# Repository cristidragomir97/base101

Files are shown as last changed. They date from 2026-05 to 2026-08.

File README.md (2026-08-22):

# base101

<p align="center">
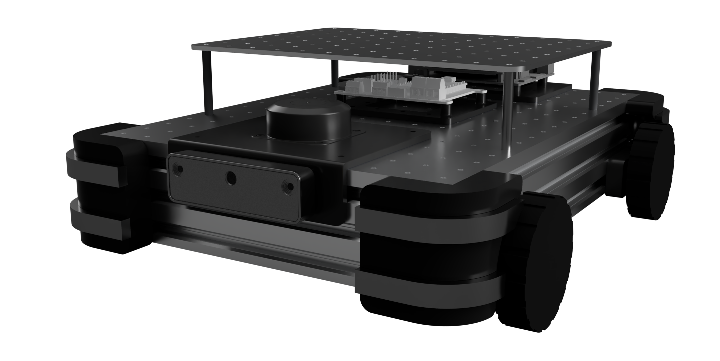
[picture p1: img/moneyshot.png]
base101
      
</p>

**An open-source mobile base you can actually build things on.**

Every robot project that has to *move* starts the same way: you want to work on
the interesting part — the arm, the perception, the behaviour — and instead you
spend six weeks building a cart. Then you want to add a lidar, and there's
nowhere to put it. Then you add a compute board, and you're drilling into your
own chassis. Most open mobile bases are somebody's finished robot, published as
if it were a platform, and the moment your payload differs from theirs you're
forking it.

base101 is the other thing: a chassis whose entire job is to carry whatever you
bolt to it. A machined deck with a grid of tapped holes, four direct-drive hub
motors, a lidar and a depth camera already wired into ROS 2, and a one-line
mounting point for the [mod101](https://github.com/robocore-dev/mod101) arm. It
drives, maps and navigates on day one, so the part you actually care about can
start on day two.

- 🧱 **Real frame, not a printed box** — 60×20 aluminum extrusion, PLA-CF printed parts only where they earn their place.
- 🕳️ **A deck you can bolt anything to** — 280×400 mm aluminum plate, 3 mm thick, CNC-machined ORP compatible grid. 
- 💥 **TPU corners** — printed bumpers absorb the collisions you're going to have, and spare your furniture while you tune the planner.
- 🛞 **4WD skid steer on hub motors** — four Waveshare DDSM210 direct-drive hubs. No gearboxes, no belts, nothing to slip: the wheel *is* the motor.
- 💪 **Sized for a 5–8 kg robot** — 97 N of tractive force at stall, enough to push 8 kg up a 10% incline. Arm, battery and compute, and it still clears the threshold into the next room.
- 🛰️ **360° lidar** — RPLidar C1 up front, `/scan` at ~10 Hz into SLAM and Nav2. Mapping and autonomous nav work out of the box.
- 👁️ **Swappable depth camera** — RealSense D435 or Luxonis OAK-D on the same bracket, one launch arg apart. Same topics, same frames.
- 🧠 **One board runs the base** — built around the [link101](https://github.com/robocore-dev/link101-hw)
- 🤖 **Carries the [mod101](https://github.com/robocore-dev/mod101) arm** — one xacro line, plus MoveIt config for the *composed* robot: the arm knows the chassis it stands on.

**Here to build the robot?** The hardware is described below. **Here to run the
code?** Start with [Getting started](#getting-started).

---

## Getting started

You'll need ROS 2 Jazzy on Ubuntu 24.04. Everything else (Gazebo Harmonic,
`ros2_control`, `gz_ros2_control`) comes from apt.

**Just the chassis** — no arm, nothing else to build first:

```bash
cd ~/robots/base101
colcon build --symlink-install --cmake-args -DPython3_EXECUTABLE=/usr/bin/python3
source install/setup.bash

ros2 launch base101_bringup_gazebo sim.launch.py
```

That's a robot in Gazebo, driving, scanning, publishing `/odom` — open
`http://localhost:8888/` and drive it around from the browser.

**With the arm**, mod101 has to be built and sourced first (it's the underlay;
base101 sits on top of it):

```bash
cd ~/robots/mod101 && colcon build --symlink-install && source install/setup.bash
cd ~/robots/base101
colcon build --symlink-install --cmake-args -DPython3_EXECUTABLE=/usr/bin/python3
source install/setup.bash

ros2 launch base101_bringup_gazebo sim.launch.py arm:=true
```

**This is the only place the build is documented** — everything below assumes
you've run it. Two footnotes that will save you an afternoon:

- **The `Python3_EXECUTABLE` pin isn't arm-specific.** It applies to every build
  here, and it guards against a stray non-system python on `PATH` breaking
  ament's `package.xml` parsing and `rosidl`'s `em` import. Tired of typing it?
  Set it once in `~/.colcon/defaults.yaml` — see [`HARDWARE.md`](HARDWARE.md).
- **`rosdep` has never heard of `mod101_description`.** base101 deliberately
  does not declare it (the arm include sits inside a `<xacro:if>`, so an
  armless workspace never resolves it), but if you run `rosdep install` with
  mod101 present, pass `--skip-keys mod101_description`.

### Things to try

```bash
ros2 launch base101_bringup_gazebo sim.launch.py                    # bare chassis, sticky_floor world
ros2 launch base101_bringup_gazebo sim.launch.py arm:=true          # chassis + 1 mod101 arm
ros2 launch base101_bringup_gazebo sim.launch.py world:=empty.sdf   # pick a world
ros2 launch base101_bringup_gazebo sim.launch.py camera:=oak_d      # Luxonis OAK-D instead of the D435
ros2 launch base101_bringup_gazebo sim.launch.py nav:=false         # no SLAM/Nav2, just the robot
ros2 launch base101_bringup_gazebo sim.launch.py agent:=false       # no robocore agent
ros2 launch base101_bringup_hw     display.launch.py                # rviz only, no sim
```

`camera:=realsense|oak_d` picks which depth module hangs off the front bracket
(default `realsense`). It only swaps the mesh and the simulated FOV — topics
stay `/base_camera/*` and frames stay `camera_link` / `camera_optical_frame`
either way, so nothing downstream notices. Both `sim.launch.py` and
`display.launch.py` take it.

SLAM, Nav2 and the robocore agent all come up with the sim by default
(`nav:=false` / `slam:=false` / `agent:=false` to skip). Nav2 alone is inert —
it blocks in `Activating` until something publishes the `map` frame — so SLAM
and Nav2 start together.

The agent picks its profile from `engine/profiles/` by configuration:
`base101.yaml` armless, `base101_arm.yaml` with `arm:=true`. Override with
`profile:=/path/to.yaml` or `$ROBOCORE_PROFILE`; it serves JSON-RPC on
`ws://:10101` and `/tmp/robocore.sock` (`agent_port:=` / `agent_socket:=`).

Manual test procedures for every variant, tool and launch combination are in
[`docs/testing.md`](docs/testing.md).

### On the real robot

Motors, IMU and lidar all hang off the Axon 2 board and talk to ROS 2 over
zenoh, so bringup is two lines:

```bash
export RMW_IMPLEMENTATION=rmw_zenoh_cpp
ros2 launch base101_bringup_hw robot.launch.py
```

Firmware, the zenoh router, serial devices and udev rules:
[`HARDWARE.md`](HARDWARE.md).

## Adding the mod101 arm

**The whole point of the deck is that something goes on it.** The obvious
something is [mod101](https://github.com/robocore-dev/mod101), a 5+1 DOF arm
that's designed to be embedded — it's a prefix-parameterised xacro macro, so
base101 mounts it with one call and gets joints `arm_1…6`.

```bash
ros2 launch base101_bringup_gazebo sim.launch.py arm:=true                   # jaws gripper
ros2 launch base101_bringup_gazebo sim.launch.py arm:=true arm_tool:=parallel
ros2 launch base101_bringup_hw display.launch.py arm:=true                   # rviz only
```

You don't configure the arm here. Rail lengths, servo mounts and the active
tool all come from `mod101_config.xacro` — whatever mod101's web configurator
last saved. Resize the arm over there, rebuild here, done.

### How the two repos meet

mod101 is an **underlay**: built and sourced first, it puts its packages on
`AMENT_PREFIX_PATH`, and base101 is the overlay on top. **Nothing in mod101
knows base101 exists.** base101 reaches back across the boundary in exactly
three places:

| Crossing | Where, in base101 | What it pulls from mod101 |
|---|---|---|
| **Geometry** | `base101_description/urdf/arm.xacro` | `<xacro:mod101_arm prefix="arm_" parent="top_plate_1">` from `mod101_macro.xacro` |
| **Semantics** | `base101_arm_moveit_config/srdf/base101_arm.srdf.xacro` | `<xacro:mod101_arm_srdf prefix="arm_" tool=…>` from `mod101_moveit_config` |
| **Build args** | both files above | `mod101_config.xacro` — rail lengths, servo mounts, active tool |

Two macro calls and one config file. No forked packages, no vendored meshes, no
duplicated URDF — which is what let the (now parked) dual-arm tower mount the
*same* macro twice, `left_arm_` / `right_arm_`, with zero changes upstream.

Two things worth knowing before they confuse you:

- **Only the `arm` variant crosses over.** The `simple` variant never touches
  the underlay, so a bare-chassis build needs no mod101 at all.
- **The prefix renames everything the macro emits.** `joint_base` becomes
  `arm_joint_base`, and the planning group `arm` becomes **`arm_arm`**. Every
  base101 config keys on the prefixed names. It reads badly and it is correct.

### Motion planning

```bash
ros2 launch base101_bringup_gazebo sim.launch.py arm:=true moveit:=true   # gazebo + move_group
```

This config exists because mod101's own only knows arm-vs-arm collisions — but
the arm can reach every part of the chassis it's bolted to, so the composed
robot needs its own self-collision matrix. The planning scene knows the robot,
not the world; [`docs/obstacle-awareness.md`](docs/obstacle-awareness.md)
covers where perceived obstacles should live relative to a picking layer.

One gotcha: the sim has to run with `arm_control:=moveit` so it spawns
`FollowJointTrajectory` controllers instead of the `Float64MultiArray` ones the
web sliders use — `moveit:=true` forces that for you. Details in
[`base101_arm_moveit_config/README.md`](src/base101_arm/base101_arm_moveit_config/README.md).

**Controllers** — arm and gripper are
`position_controllers/JointGroupPositionController`, commanded with
`std_msgs/Float64MultiArray` on `/<name>/commands`:

| Controller | Joints |
|---|---|
| `arm_controller` | `arm_joint_base, arm_joint_shoulder, arm_joint_elbow, arm_joint_wrist_tilt, arm_joint_wrist_roll` |
| `gripper_controller` | `arm_6` (the tool joint) |
| `diff_drive_controller` | wheels (via `twist_mux`) |

The wrist camera is bridged as `/arm_wrist_camera/image_raw`.

## Driving it from a browser

No joystick, no terminal, no extra install — two ways:

- **rosboard's "Joint sliders" card** (the good one): open
  `http://localhost:8888/`, pick **Joint sliders** in the System nav. One panel,
  a position slider for every controlled joint, initialised from the live robot
  pose with readouts and a re-sync button. Groups whose hardware isn't loaded
  hide themselves, and the card survives a reload. Base driving lives on the
  separate **Teleop** card. (Position commands deliberately *aren't* zeroed by
  the publish watchdog the way Twist is, so the arm holds its pose when the
  browser goes quiet.)
- **`base101_teleop`** — a zero-dependency fallback if rosboard is unhappy:
  `ros2 run base101_teleop server` → `http://localhost:8700/`. Same sliders plus
  a hold-to-drive base pad. See
  [`src/base101_teleop/README.md`](src/base101_teleop/README.md).

## Simulation

The robot runs in **Gazebo Sim** through `gz_ros2_control`, and the sim is
meant to be the default place you work — it publishes the same `/cmd_vel_*`,
`/odom`, `/scan`, `/joint_states` and `/base_camera/image_raw` topics the real
robot does, so code written against sim moves over unchanged.

Each variant takes a `simulator` xacro arg (`gazebo` | `none`) that decides
whether the URDF carries the sim `ros2_control` and extension tags; `none` is
the bare URDF for rviz and real hardware. Worlds and the gz↔ros bridge config
live in the shared `base101_worlds` package.

## How the workspace is put together

*Skip this unless you're adding a package — everything above works without it.*

It's a **shared core** plus one self-contained stack per **variant**
(`description` / `gazebo` / `control`). Variants are grouped into folders under
`src/` (`base101/`, `base101_arm/`); colcon discovers packages recursively, so
the folders are purely organisational. Packages parked out of the build live in
[`attic/`](attic/README.md).

**Model, config and worlds** — `src/base101/`

| Package | Type | Purpose |
|---|---|---|
| `base101_description` | ament_python | **The robot**: `base101.xacro` (one description, `arm:=` picks the configuration), chassis links/joints, sensors, materials, meshes. *Not launched directly.* |
| `base101_control` | ament_cmake | Tuning: `controllers.{sim,hw}.yaml`, `twist_mux.yaml`, and the hardware overlay `base101.hardware.xacro`. |
| `base101_control_plugin` | ament_cmake | `ros2_control` SystemInterface bridging wheel/arm/camera command+state interfaces to the Axon firmware's `/motor_manager/*` topics (zenoh). |
| `base101_worlds` | ament_cmake | Sim-common assets: Gazebo worlds, ros↔gz bridge, RViz preset. |

**Stacks** — own their own launch, composed by the bringup packages

| Package | Type | Purpose |
|---|---|---|
| `base101_slam` | ament_cmake | EKF (robot_localization) + slam_toolbox: `/map` and the `map->odom` TF. |
| `base101_nav` | ament_cmake | Nav2: planner, controller, bt_navigator, velocity smoother, behavior trees. |
| `base101_arm_moveit_config` | ament_cmake | `src/base101_arm/` — MoveIt semantics for the composed chassis+arm robot, and `move_group.launch.py`. |

**Bringup** — the only launches you type

| Package | Type | Purpose |
|---|---|---|
| `base101_bringup_gazebo` | ament_cmake | `sim.launch.py` — the whole robot in Gazebo: model, controllers, bridges, SLAM, Nav2, optionally arm + MoveIt. |
| `base101_bringup_hw` | ament_cmake | `robot.launch.py` — the same graph on real hardware, same argument names. Also owns `display.launch.py` (RViz only). |

Arm or no arm is the `arm:=` argument, not a package. Before the 2026-08
restructure it was six packages (`base101_simple_{description,gazebo,control}`
and `base101_arm_{description,gazebo,control}`) expressing one boolean — see
[`docs/bringup-restructure.md`](docs/bringup-restructure.md).

**Other tooling** — `src/`

| Package | Type | Purpose |
|---|---|---|
| `robocore_agent` | ament_python | Robocore (blueprint engine) agent: ROS interface, task/safety model, Nav2 + SLAM managers, sensor streams. Launched by both bringup packages (`agent:=false` to skip); commands `/cmd_vel_agent` at twist_mux priority 50. |
| `base101_mcp` | ament_python | Generic ROS2 ↔ MCP (Model Context Protocol) bridge. Lets Claude (or any MCP client) discover topics/services and read/publish messages over natural language. Requires `pip install "fastmcp>=2,<3"`. |
| `base101_teleop` | ament_python | Standalone single-page web teleop (base + every joint) on `:8700`. Fallback for the rosboard Joint sliders card. |
| `rosboard` | ament_python | Vendored web dashboard. Carries two publisher cards: **Teleop** (Twist) and **Joint sliders** (Float64MultiArray position commands for tower + arms). |

```mermaid
graph TD
    subgraph bringup["bringup — what you launch"]
        SIM["base101_bringup_gazebo<br/><i>sim.launch.py</i>"]
        HW["base101_bringup_hw<br/><i>robot.launch.py, display.launch.py</i>"]
    end

    subgraph stacks["stacks — own launch, composed above"]
        SLAM["base101_slam<br/><i>EKF + slam_toolbox</i>"]
        NAV["base101_nav<br/><i>Nav2</i>"]
        MOVEIT["base101_arm_moveit_config<br/><i>move_group</i>"]
    end

    subgraph model["model, config, worlds"]
        DESC["base101_description<br/><i>base101.xacro + arm.xacro,<br/>chassis, sensors, meshes</i>"]
        CTRL["base101_control<br/><i>controllers.{sim,hw}.yaml,<br/>twist_mux, hardware xacro</i>"]
        PLUGIN["base101_control_plugin<br/><i>ros2_control ↔ Axon bridge</i>"]
        GZ["base101_worlds<br/><i>worlds, gz bridge, rviz</i>"]
    end

    MOD["mod101_description<br/><i>(underlay, arm:=true only)</i>"]

    SIM --> DESC & CTRL & GZ
    HW  --> DESC & CTRL
    SIM -.->|composes| SLAM & NAV & MOVEIT
    HW  -.->|composes| SLAM & NAV

    DESC -->|arm:=true, inside xacro:if| MOD
    CTRL -->|hardware xacro| PLUGIN
    DESC -.->|gz plugin loads controllers.sim.yaml| CTRL
```

Solid arrows are build/`xacro:include` dependencies; dashed arrows are runtime
composition — the bringup packages including a stack's launch file, and the
`gz_ros2_control` controller-file lookup resolved at Gazebo spawn.

## Deeper docs

**Use it**

- **[`HARDWARE.md`](HARDWARE.md)** — real-robot bringup: Axon 2 firmware, the zenoh router, serial devices, udev
- **[`docs/testing.md`](docs/testing.md)** — manual test procedures for every configuration, tool and launch combination
- **[`docs/findings-open.md`](docs/findings-open.md)** — known-open issues: the arm has no hardware path, an unconfirmed cold-map nav abort, an inflation-radius warning
- **[`docs/bringup-restructure.md`](docs/bringup-restructure.md)** — why there are two bringup packages and one description

**Build on it**

- **[`src/base101_arm/base101_arm_moveit_config/README.md`](src/base101_arm/base101_arm_moveit_config/README.md)** — motion planning for the composed robot, and the sync step after the arm is reconfigured
- **[`src/base101/base101_description/README.md`](src/base101/base101_description/README.md)** — the shared chassis library
- **[`docs/robocore-camera-frames.md`](docs/robocore-camera-frames.md)** — camera frame conventions, and the `optical: true` change robocore-sdk still needs
- **[`docs/obstacle-awareness.md`](docs/obstacle-awareness.md)** — where perceived obstacles should live relative to a picking layer

**History** — kept for reasoning, not as current documentation

- **[`docs/worklogs/dual_arm.md`](docs/worklogs/dual_arm.md)** — dual-arm integration: mount-point measurement, the arm-yaw fix, the stale-`robot_state_publisher` gotcha
- **[`docs/worklogs/tower.md`](docs/worklogs/tower.md)** — the parked cross tower
- **[`docs/worklogs/nav.md`](docs/worklogs/nav.md)**, **[`docs/worklogs/nav_restructure.md`](docs/worklogs/nav_restructure.md)** — Nav2 + slam_toolbox porting notes, and why the two stacks are deliberately independent

## Related Projects

- **[mod101](https://github.com/robocore-dev/mod101)** — 5+1 DOF modular robot arm
- **[Axon](https://github.com/robocore-dev/axon)** — Multi-protocol controller board
- **[Forge](https://github.com/robocore-dev/forge)** — ROS2 deployment orchestration

## License
MIT

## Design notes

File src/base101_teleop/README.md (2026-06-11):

# base101_teleop

Single-page web teleop for the base101 dual-arm robot. One panel with
everything: a hold-to-drive base pad plus a position slider for every
controlled joint — lift, pan/tilt head, both mod101 arms, both grippers.

Zero dependencies beyond `rclpy`: one python file with the HTML embedded,
served by the stdlib HTTP server. This is the standalone fallback for the
rosboard **Joint sliders** card (which is the recommended UI — see the
workspace README).

## Run

```bash
ros2 run base101_teleop server                       # http://localhost:8700/
ros2 run base101_teleop server --ros-args -p port:=9000
```

## What it publishes

| UI | Topic | Type |
|---|---|---|
| Base pad | `/cmd_vel_key` (twist_mux, priority 90) | `geometry_msgs/Twist` |
| Tower sliders | `/tower_controller/commands` | `std_msgs/Float64MultiArray` `[lift, head_pan, head_tilt]` |
| Arm sliders | `/<side>_arm_controller/commands` | `Float64MultiArray` `[<side>_arm_1 … _5]` |
| Gripper slider | `/<side>_gripper_controller/commands` | `Float64MultiArray` `[<side>_arm_6]` |

Sliders always send the **full group array** (untouched joints keep their
slider value). The base pad republishes at 10 Hz while held and zeroes on
release; twist_mux's 0.5 s timeout acts as the dead-man stop.

## Behavior notes

- The page builds itself from a `/joint_states` snapshot (`GET /state`), so
  sections for hardware that isn't loaded (no tower, no arms) don't render,
  and sliders initialise to the robot's actual pose. "Sync sliders to
  robot" re-pulls at any time.
- Plain HTTP polling — no rosbridge, no websockets. `POST /cmd` carries the
  commands; see the docstring in `base101_teleop/server.py` for payload
  shapes.

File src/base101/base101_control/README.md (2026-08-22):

# base101_control

`ros2_control` configuration and bringup for the base101. Owns the
controller_manager configs, the `twist_mux` priority table, and the
hardware-overlay xacro. Configuration only — the launches that consume it
live in `base101_bringup_gazebo` and `base101_bringup_hw`.

## What's here

```
config/
├── controllers.sim.yaml            # wheels + arm, every configuration, one file
├── controllers.hw.yaml             # real-hardware controllers (wheels only, see below)
└── twist_mux.yaml                  # /cmd_vel priority table

urdf/
└── base101.hardware.xacro          # wraps base101.xacro with simulator:=none
                                    # + the Axon bridge ros2_control block
```

`controllers.sim.yaml` declares the arm controllers alongside the wheel ones.
Declaring a controller only makes it spawnable by name, so an armless robot
never spawns them and the extra entries cost nothing.

## /cmd_vel routing

`twist_mux` arbitrates between three Twist sources by priority. Inputs are
plain `geometry_msgs/Twist`; the output is `geometry_msgs/TwistStamped`
(diff_drive_controller in Jazzy is stamped-only) on
`/diff_drive_controller/cmd_vel`.

| Source | Topic | Priority |
|---|---|---|
| Joystick (rosboard teleop card, base101_teleop_web) | `/cmd_vel_joy` | 100 |
| Keyboard | `/cmd_vel_key` | 90 |
| Navigation (Nav2) | `/cmd_vel_nav` | 10 |

Higher priority wins; lower-priority commands are timed out at 0.5s. This
table is identical across simulators — every backend has `twist_mux`
producing on `/diff_drive_controller/cmd_vel`.

## Sim vs hardware

The same `diff_drive_controller` runs in sim (Gazebo, MuJoCo) and on real
hardware. What changes is the ros2_control SystemInterface that owns the
joints:

| Backend | Plugin | URDF generated by |
|---|---|---|
| Gazebo | `gz_ros2_control/GazeboSimSystem` | `base101_description/urdf/base101.xacro` with `simulator:=gazebo` |
| MuJoCo | `mujoco_ros2_control/MujocoSystem` | same, with `simulator:=mujoco` |
| Real HW | `base101_control_plugin/ROS2ControlBridge` (Axon 2 firmware over zenoh) | `urdf/base101.hardware.xacro` |
| Isaac Sim | — | OmniGraph drives joints natively, no ros2_control |

So `controllers.sim.yaml` works as-is for both Gazebo and MuJoCo; they just
bind to different hardware plugins. Isaac Sim ignores this config — see
`base101_isaac` for its routing.

**The arm is sim-only.** `controllers.hw.yaml` has no arm section and
`base101.hardware.xacro` emits a `ros2_control` block for the four wheel
joints only, so there is nothing for an arm controller to claim on the real
robot. `base101_bringup_hw` refuses `arm:=true` for that reason — see
[`docs/findings-open.md`](../../../docs/findings-open.md) #3.

## Real-hardware bringup

```bash
export RMW_IMPLEMENTATION=rmw_zenoh_cpp
ros2 launch base101_bringup_hw robot.launch.py
```

Start the host zenoh router and `rmw_zenoh` first — see
[`HARDWARE.md`](../../../HARDWARE.md).

## Keeping wheel geometry in sync

`wheel_separation` and `wheel_radius` are duplicated across:

- `config/controllers.sim.yaml` and `config/controllers.hw.yaml`
- `base101_mujoco/scenes/*.xml`
- `base101_isaac/launch/isaac.launch.py` (the `WHEEL_GEOMETRY` dict)

If you tweak one, tweak all three. There's no single source of truth
today because each simulator wants the numbers in its own format.

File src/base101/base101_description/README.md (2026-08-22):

# base101_description

**The robot.** The common base — extrusion frame, wheels, mounts, bumpers,
lidar, camera, compute tray, the `top_plate_1` deck — plus materials, sensors,
meshes, and the top-level assembly that turns them into a complete robot.

`base101.xacro` is the entry point. One description for every configuration:

| Argument | Values | Adds |
|---|---|---|
| `arm` | `false` (default) / `true` | one mod101 arm on `top_plate_1` |
| `camera` | `realsense` (default) / `oak_d` | which depth module is on the front bracket |
| `simulator` | `gazebo` / `mujoco` / `isaac` / `none` | which ros2_control + extension tags to emit |
| ~~tower~~ | — | *parked* — see [attic](../../../attic/README.md) |

Before the 2026-08 restructure this was a parts library and each variant had
its own assembly package; `arm` is now an argument, not a package. See
[`docs/bringup-restructure.md`](../../../docs/bringup-restructure.md).

You still don't launch this package — the bringup packages do
(`base101_bringup_gazebo`, `base101_bringup_hw`). See the top-level
[README](../../../README.md) for the package-structure graph.

**`arm.xacro` must stay inside its `<xacro:if>`.** It resolves
`$(find mod101_description)`, and keeping the include conditional is what lets
an armless workspace build and run with no mod101 underlay at all.

## Files

```
urdf/
├── chassis.xacro                 # chassis link/joint tree (the shared fragment)
├── chassis.gazebo                # gazebo-only extensions: sensors (imu/lidar/camera),
│                                 #   materials, wheel friction — NO gz_ros2_control plugin
├── chassis.gazebo.ros2control    # wheel ros2_control system (gz_ros2_control/GazeboSimSystem)
├── chassis.mujoco.ros2control    # wheel ros2_control system (mujoco_ros2_control/MujocoSystem)
└── materials.xacro               # shared material definitions

meshes/                           # chassis STLs (flat — one variant's worth: simple == base)
config/
└── display.rviz                  # RViz preset reused by the variants' display launches
scripts/
├── import_cad_export.py          # fold a fresh Fusion export into meshes/
├── mass_properties.py            # integrate mass/COM/inertia off a mesh
├── collision_primitives.py       # swap <collision> meshes for boxes/cylinders
└── decimate_meshes.py            # quadric-error decimation of the visual STLs
```

Those four run in that order, and the order matters: `mass_properties` needs
watertight meshes to integrate a volume, and `decimate_meshes` deliberately
gives that up (see below).

The variant top-level xacros own the per-simulator dispatch and the
`gz_ros2_control` plugin block (which points at that variant's
`controllers.sim.yaml`), so this package carries no controller-file reference.

## Arguments

| arg | values | default | effect |
|---|---|---|---|
| `camera` | `realsense`, `oak_d` | `realsense` | which module hangs off the edge bracket |

The bracket takes either an Intel RealSense D435 or a Luxonis OAK-D on the same
face. Only the selected one is instantiated, but `camera_link` and
`camera_optical_frame` exist either way and the sim topics stay `/base_camera/*`,
so nothing downstream has to branch. The two differ in body depth (the D435
stands ~8 mm further proud) and in HFOV (87° vs 69°, wired into `chassis.gazebo`).

## Frames

| frame | where it is | who consumes it |
|---|---|---|
| `base_link` | wheel contact plane, centred on the chassis | odom, nav, diff_drive |
| `lidar_frame` | RPLidar C1 rotor axis, 96.5 mm off the floor | `/scan`, slam, nav |
| `camera_link` | front face of the fitted camera, +X out of the lens | `/base_camera/*` |
| `camera_optical_frame` | REP-103 twist of `camera_link` | point clouds |
| `imu_link` | on the link101 PCB, 99 mm up and 10 mm back | `/sensors/imu`, EKF |

`base_link` sits *on the ground*, not on the deck — a chassis-height origin
would shift every costmap and camera height downstream. The CAD origin is the
top of the extrusion box, 81.965 mm up, so `chassis.xacro` drops the root by
exactly that much and leaves every other position at its exported value.

## Re-importing a CAD export

The Fusion export is a flat pile of STLs in global assembly coordinates plus a
machine-generated URDF. `scripts/import_cad_export.py <export-dir>` handles the
mesh half:

- **The right-hand wheels come out misnamed.** Fusion's `wheel_back_right_1` is
  physically at the front. The two files are swapped on import.
- **The deck standoffs come out as `standoff2/3/4`**, which says nothing about
  which corner they are. They are renamed after their corner.
- **Each wheel is exported as one rigid body.** The DDSM210 is a hub motor: the
  stator boss is bolted into the printed mount and does not turn. The mesh
  splits cleanly (boss at r ≤ 12.5 mm, rim at r ≥ 35 mm), so the importer cuts
  each wheel at r = 20 mm into a fixed `wheel_hub_*` and a turning `wheel_*`,
  capping both halves so they stay watertight.

The URDF half is folded in by hand. Things to redo when the geometry moves:
the `base_link` drop to the contact plane, the wheel joint names and axes, the
five hand-placed frames in the table above, and any link the export left at
`mass="0"` (`scripts/mass_properties.py` prints a ready-made `<inertial>`).

## Collision geometry

**No link uses a mesh for `<collision>`, and `self_collide` is off everywhere.**
Both are deliberate and both are load-bearing for how fast the sim runs.

The CAD export gives every link the same mesh for visual and collision, which
put 216k triangles into the physics engine for a chassis that is, geometrically,
a box on four cylinders. Gazebo and MoveIt/FCL build a BVH per collision body
and re-test them every step, so the RealSense housing (54k), the lidar can
(51k), the link101 PCB (40k) and the Orin (26k) — four bodies sealed inside the
shell that nothing can ever touch — were 80% of the budget. `self_collide` then
multiplied it: 26 links joined by fixed joints, so ~325 pairs of full-resolution
meshes tested per step to discover that a rigid frame is still rigid.

Now: 21 boxes + 9 cylinders, **0 collision triangles**, no self-collision pairs.
Visual meshes are untouched — a GPU does not care about 216k triangles.

`scripts/collision_primitives.py` regenerates the primitives from the meshes
(bounds taken in each link's own frame); the shape per link is the `SHAPES`
table at the top of it. Re-run it after a CAD re-import:

```bash
python3 scripts/collision_primitives.py urdf/chassis.xacro --report   # dry run
python3 scripts/collision_primitives.py urdf/chassis.xacro --write
```

The wheel cylinders are the one shape worth checking by hand after a re-import
— the contact patch is what the drivetrain pushes against. The hubs get no
collision at all, and neither should anything else that lives inside the shell.

## Visual meshes

The export tessellates for manufacturing tolerance, not for rendering, so the
STLs arrive far denser than anything needs: 272k triangles, 14 MB.
`scripts/decimate_meshes.py` runs quadric-error decimation over them at a
0.5 mm surface tolerance, which brings that to 60k triangles and 3.0 MB with a
worst-case bounding-box drift of 0.1 mm.

```bash
python3 scripts/decimate_meshes.py meshes/ --tolerance 0.5 --report   # dry run
python3 scripts/decimate_meshes.py meshes/ --tolerance 0.5 --write
```

It allows topology change by default, which is the setting that actually does
the work: the classic link condition keeps a mesh watertight but forbids ever
closing a hole, so a 3.4 mm bolt hole in a 340 mm plate survives at any
tolerance. Decimated meshes are therefore **not watertight** — fine, because
by this point collision is primitives and nothing integrates over them. Pass
`--watertight` if you need closed meshes back (it reduces much less), and run
`mass_properties.py` *before* decimating, not after.

`base_link` is the stubborn one: it only reduces 34%, because it is genus 199
— the M3 tapped grid means nearly every vertex sits on a hole boundary. That
grid is the part's defining feature, so leave the tolerance where it is rather
than dissolving it.

## Things to remember when editing the chassis

- **Joint names are the binding contract** with every other package. The four
  wheels are exactly `front_left_wheel_joint`, `front_right_wheel_joint`,
  `back_left_wheel_joint`, `back_right_wheel_joint`. Renaming one ripples into
  every variant's `controllers.sim.yaml` and `chassis.*.ros2control`.
- **All four wheel joints use axis +Y**, including the right-hand pair (the raw
  export flips them), so a positive diff_drive command drives forward on both
  sides.
- **`top_plate_1` is the deck every add-on parents to.** It is now 180 × 240 mm
  and rides 45 mm of standoff (130 mm off the floor); the previous export had a
  340 × 240 mm plate sitting straight on the extrusion at 82 mm. That change
  made the arm overlay's own mount deck redundant — it was an
  identical 180 × 240 plate on identical 45 mm standoffs, stacked on this one —
  so the arm now bolts directly here. Moving or renaming `top_plate_1` ripples
  into that package.
- `<gazebo>` extensions in `chassis.gazebo` are only included on the gazebo
  branch of each variant xacro, so they don't affect the `none` (rviz / real
  hardware) build.
- Wheel separation / radius live in each variant's `controllers.sim.yaml` —
  keep them in sync with the URDF geometry. Measured off the current meshes:
  track 0.2899 m (rim mid-planes), rolling radius 0.036 m, wheelbase 0.2393 m.
- **The exported inertials are all steel.** Fusion had no materials assigned,
  so every body came out at ~7850 kg/m³ and the chassis totals 14 kg against a
  real ~5 kg. They are kept as exported (the sim contact params were tuned
  against numbers of this order) but they are not physical — worth a pass with
  real densities if the sim dynamics ever start to matter.

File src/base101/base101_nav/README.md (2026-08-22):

# base101 Navigation Package

Pure Nav2 stack for the base101 robot: planner, controller, bt_navigator,
velocity smoother. Restructured for robocore autonomy (see
`docs/worklogs/nav_restructure.md`): one always-on launch, no modes, no
mode_manager, no behavior_server, no AMCL, no explore_lite.

SLAM and odometry fusion live in **base101_slam**. The two stacks are
deliberately independent — each has its own lifecycle manager and neither
package depends on the other. Nav2 consumes `/map` and the `map->odom`
TF from whatever publishes them (slam_toolbox here) and starts fine
before they exist.

## Quick Start

Normally you don't launch this yourself — the bringup packages compose it,
and it comes up with the sim by default:

```bash
ros2 launch base101_bringup_gazebo sim.launch.py       # sim + slam + nav2
ros2 launch base101_bringup_hw     robot.launch.py     # robot + slam + nav2
```

Launching the halves by hand is still supported, and is the point of keeping
them independent — it's how you restart Nav2 without disturbing the map:

```bash
colcon build --packages-select base101_nav base101_slam
source install/setup.bash

# The robot's body, without any autonomy
ros2 launch base101_bringup_gazebo sim.launch.py nav:=false slam:=false

# SLAM half (mapping by default; localization via service switch)
ros2 launch base101_slam slam.launch.py use_sim_time:=true

# Nav2 half
ros2 launch base101_nav nav.launch.py use_sim_time:=true
```

**Nav2 on its own does nothing visible.** It blocks in `Activating` until
something publishes the `map` frame, so `nav.launch.py` without
`slam.launch.py` (or another map source) looks like a launch that hangs.

## Design

- **Modes are service calls, not process restarts.** slam_toolbox starts
  in mapping mode; the robocore bridge switches to localization via
  `/slam_toolbox/deserialize_map` and saves maps via
  `/slam_toolbox/serialize_map` + `map_saver_cli`.
- **No recovery behaviors in ROS.** The BT is plan/follow/fail
  (`behavior_trees/nav_to_pose.xml`): Nav2 returns ABORTED on any
  failure, the bridge yields `NavStatus(phase="stuck")`, and the Python
  mission decides what happens next. The bridge clears both costmaps
  before each goal via `/global_costmap/clear_entirely_global_costmap`
  and `/local_costmap/clear_entirely_local_costmap`. No spinning — the
  tower and arms make it dangerous.
- **One costmap config for all modes** (`config/costmap.yaml`):
  slam_toolbox always publishes `/map`, so the static layer always has a
  map — growing while mapping, fixed when localized.
- **cmd_vel topology:** controller → `cmd_vel_raw` → velocity_smoother →
  `cmd_vel_nav` → twist_mux (priority 10, below agent teleop at 50 and
  joystick at 100).

## Configuration Files

| File | Purpose |
|---|---|
| `planner.yaml` | SmacPlanner2D global path planning |
| `controller.yaml` | MPPI controller for trajectory following |
| `costmap.yaml` | Unified global/local costmaps (all modes) |
| `bt_navigator.yaml` | Behavior tree navigator config |
| `velocity_smoother.yaml` | Velocity command smoothing |
| `laser_filter.yaml` | Scan filter config (not currently launched) |

## Robot Parameters

The configuration is tuned for the base101 robot (differential drive, DDSM115 wheels):
- Wheel separation: 0.38 m
- Wheel radius: 0.05035 m (100.7 mm wheel)
- Max linear velocity: 0.8 m/s (controller cap; hw allows 1.5)
- Max angular velocity: 1.5 rad/s (controller cap; hw allows 2.5)
- Footprint: ~50cm x 48cm rectangle (refine against CAD)

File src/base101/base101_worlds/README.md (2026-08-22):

# base101_worlds

Sim-common **assets** for base101. No launch files, no nodes — just the
things a sim bringup reads.

```
worlds/empty.sdf          bare ground plane + physics/sensor systems
worlds/sticky_floor.sdf   default world: high-friction floor, gz IMU system
config/gz_ros_bridge.yaml ros_gz_bridge topic map (lidar, cameras, IMU, odom)
config/gazebo.rviz        RViz preset for looking at the sim
```

The launch that consumes all of this is
`base101_bringup_gazebo/launch/sim.launch.py`:

```bash
ros2 launch base101_bringup_gazebo sim.launch.py
ros2 launch base101_bringup_gazebo sim.launch.py world:=empty.sdf
ros2 launch base101_bringup_gazebo sim.launch.py arm:=true
```

`world:=` takes either a bare filename from `worlds/` or an absolute path.

Renamed from `base101_gazebo` in the 2026-08 bringup restructure — the old
name sat one letter away from `base101_bringup_gazebo` and the two were
constantly confused. See `docs/bringup-restructure.md`.

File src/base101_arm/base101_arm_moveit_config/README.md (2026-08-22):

# base101_arm_moveit_config

MoveIt2 semantics for the **composed** robot: the base101 chassis with one
mod101 arm on its deck.

## Why this exists separately from mod101_moveit_config

mod101 ships a complete MoveIt config for the arm on its own. It cannot be
reused as-is for two reasons, and only the second one really matters:

1. It anchors the robot at a `world` link that exists only in the standalone
   `mod101.xacro`.
2. **Its self-collision matrix contains only arm-vs-arm pairs.** The arm reaches
   ~525 mm from a turret 186 mm up, and every chassis feature is inside that
   envelope — Orin 105 mm away (top at z=126 mm), lidar 138 mm (z=107),
   RealSense 173 mm (z=81), bumpers 206 mm (z=85). Without arm-vs-chassis pairs
   the planner will route the gripper straight through the robot's own lidar.

What this package adds is exactly those two things. The arm's own semantics are
*not* restated: mod101 exposes them as the prefix-parameterised
`mod101_arm_srdf` macro and this package instantiates it with `prefix="arm_"`.

```
srdf/base101_arm.srdf.xacro   virtual_joint -> base_link, macro at prefix arm_
config/
├── kinematics.yaml           pick_ik, position-only (5-DOF arm)
├── joint_limits.yaml         velocity/accel for time parameterisation
├── moveit_controllers.yaml   the two FollowJointTrajectory controllers
├── ompl_planning.yaml        RRTConnect default
├── moveit.rviz               fixed frame base_link, group arm_arm
└── collisions/<tool>.srdf.xacro   GENERATED — chassis pairs only
launch/
└── move_group.launch.py      move_group alone; base101_bringup_gazebo composes
                              it via sim.launch.py moveit:=true
scripts/gen_collision_matrix.py
```

## Running it

```bash
source ~/robots/mod101/install/setup.bash      # underlay first
source install/setup.bash
ros2 launch base101_bringup_gazebo sim.launch.py arm:=true moveit:=true
```

or, against a sim you already have up:

```bash
ros2 launch base101_bringup_gazebo sim.launch.py arm:=true arm_control:=moveit
ros2 launch base101_arm_moveit_config move_group.launch.py
```

`arm_control:=moveit` is not optional (`moveit:=true` sets it for you).
`base101_control/config/controllers.sim.yaml` declares two controllers per
group: `arm_controller` / `gripper_controller` take
`Float64MultiArray` and are what the web slider UIs drive, and
`arm_trajectory_controller` / `gripper_trajectory_controller` offer
`FollowJointTrajectory`, which is the only thing MoveIt can execute. Each pair
claims the same joints, so exactly one may be active.

## Group names

They are `arm_arm` and `arm_gripper`, not `arm` and `gripper` — the macro names
its groups `${prefix}arm`, and the prefix is `arm_`. Every config file keys on
the prefixed names. Cosmetically poor; fixable by giving the mod101 macro an
explicit group-name parameter if it ever grates.

## The collision matrix is generated, and "never" is statistical

`config/collisions/*.srdf.xacro` holds only pairs with at least one chassis
link — mod101 supplies the arm-internal ones and the arm's internal geometry
doesn't change by being bolted down.

It is generated rather than written because it is a property of the *build*:
the configurator can change the rail lengths, which changes the arm's reach,
which changes which pairs can never touch.

**mod101's configurator does not regenerate these for you.** It regenerates its
own matrices and then tells you to run this — the arm deliberately doesn't know
where its consumers live. After any configurator change, run:

```bash
./scripts/sync_arm_change.sh                    # all tools
./scripts/sync_arm_change.sh --tool jaws
./scripts/sync_arm_change.sh --trials 4000000
```

That sources the mod101 underlay (`MOD101_WS`, default `~/robots/mod101`) then
this workspace, so the generator reads the build args the configurator last
saved. Arguments pass straight through to `gen_collision_matrix.py`, which you
can still call directly if the environment is already set up.

**Read the trials note in that script before lowering `--trials`.** "Never
colliding" is decided by random sampling, and disabling a pair that *can*
collide is the dangerous direction. On this robot the default of 10,000 that
mod101 uses was measurably wrong — it disabled `arm_jaws_moving` against both
back standoffs and the back-left wheel. The default here is 1,000,000, which is
past the knee but still sheds about one pair per doubling at 2M.

**mod101's own matrix is *not* converged at 10k** — an earlier version of this
note claimed it was. Diffing a 10k run against a 1M run of the same build (276
pairs, not 210) shows 10k wrongly disabling real pairs on every tool, including
`base_cover_1`↔`wrist_camera_v1_1` on all four — which would let the planner
drive the wrist camera through the base cover. Run mod101's generator with
`--trials 1000000` until its default is raised.

## Not done

- No `controllers.hw.yaml`; the arm is sim-only on real hardware.
- No sensor plugin for octomap, so the planning scene has no perceived
  obstacles — self-collision and the static chassis only. Whether that belongs
  here or in a picking layer, and what it would take, is worked through in
  [`docs/obstacle-awareness.md`](../../../docs/obstacle-awareness.md).
- The virtual joint is `fixed` to `base_link`, i.e. arm-only planning with the
  base treated as stationary. Planning base motion would mean a `planar` joint
  on `odom` and a controller that can execute it.

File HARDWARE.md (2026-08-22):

# Running base101 on real hardware

base101's motors, IMU and lidar are driven by the **Axon 2 board (RP2354B)**
running the [`axon-firmware`](../axon-firmware). The firmware is a native ROS 2
node (Pico-ROS + zenoh-pico, compatible with `rmw_zenoh`): the host talks ROS
topics, not raw serial. On the host side, `ros2_control` runs the usual
`diff_drive_controller`, and `base101_control_plugin` bridges its per-wheel
command/state interfaces to the firmware's motor-manager topics.

```
diff_drive_controller ──▶ base101_control_plugin/ROS2ControlBridge
                              │  pub /motor_manager/base_cmd   (4× wheel vel, rad/s)
                              │  sub /motor_manager/joint_states
                              ▼      ── zenoh ──▶  Axon 2 firmware ──▶ 4× DDSM210
```

## Topic contract (firmware ⇄ host)

| Topic | Type | Dir | Notes |
|---|---|---|---|
| `/motor_manager/base_cmd` | `std_msgs/Float64MultiArray` | host→fw | 4 wheel velocities (rad/s), order **[FL, FR, BL, BR]** |
| `/motor_manager/joint_states` | `sensor_msgs/JointState` | fw→host | wheels in slots 0–3, 50 Hz |
| `/imu/data`, `/imu/mag`, `/imu/temperature` | `Imu` / `MagneticField` / `Temperature` | fw→host | BNO055, frame `imu_link`, 50 Hz |

**Joint names + order are a contract** with `axon-firmware/src/ros/axon_config.h`:

- names: `front_left_wheel_joint`, `front_right_wheel_joint`,
  `back_left_wheel_joint`, `back_right_wheel_joint` (used by both the URDF and
  the firmware's `joint_states`);
- `base_cmd` index order `[0]=FL [1]=FR [2]=BL [3]=BR` — this is the order the
  wheel `<joint>`s appear in `base101_control/urdf/base101.hardware.xacro`.

If you change either side, change both.

## Host one-time setup

1. **udev rules** — exposes the board as stable device names:
   ```
   cd ~/Work/axon-firmware && ./install.sh
   #  /dev/axon-zenoh  zenoh serial transport
   #  /dev/axon-lidar  RPLidar C1 UART passthrough
   #  /dev/axon-debug  firmware debug log
   ```
2. **zenoh router** — bridges the board's serial zenoh to the host's
   `rmw_zenoh` sessions (TCP 7447). Use the firmware's compose file:
   ```
   cd ~/Work/axon-firmware/docker && docker compose up -d   # uses zenoh-serial.json5
   ```
3. **rmw_zenoh** — every ROS 2 shell that should see the board:
   ```
   export RMW_IMPLEMENTATION=rmw_zenoh_cpp
   ```

## Bring up the base

```
source /opt/ros/jazzy/setup.bash
source ~/Work/base101/install/setup.bash
export RMW_IMPLEMENTATION=rmw_zenoh_cpp

ros2 launch base101_bringup_hw robot.launch.py
```

This starts `robot_state_publisher` (from `base101.hardware.xacro`, i.e.
`simulator:=none` + the Axon bridge), the `controller_manager` with
`controllers.hw.yaml`, the `joint_state_broadcaster` + `diff_drive_controller`,
a `twist_mux` in front of `/diff_drive_controller/cmd_vel`, and then SLAM +
Nav2. Add `nav:=false slam:=false` for wheels only.

Drive it:
```
ros2 topic pub /cmd_vel_key geometry_msgs/msg/Twist '{linear: {x: 0.1}}' -r 10
```

### Verify
- `ros2 control list_hardware_components` → `base101_hw_system` **active**.
- `ros2 control list_controllers` → `diff_drive_controller` + `joint_state_broadcaster` **active**.
- `ros2 topic echo /motor_manager/base_cmd` reacts to `cmd_vel`.
- `ros2 topic echo /joint_states` shows the four wheels turning; `/odom` is published.
- `ros2 topic echo /imu/data` streams from the BNO055.

### Wheel direction calibration
If forward/back or turning is inverted, flip the wheel `direction` rows in the
firmware's `axon_config.h` (all four for fwd/back; per-side for spin) and
reflash — the host side stays unchanged.

## Sensors

- **Lidar (RPLidar C1)** on the firmware passthrough port:
  ```
  ros2 run rplidar_ros rplidar_composition --ros-args \
    -p serial_port:=/dev/axon-lidar -p frame_id:=lidar_frame
  ```
- **IMU** needs no driver — the firmware publishes `/imu/data` directly.

## Navigation / SLAM

`base101_slam` and `base101_nav` run on top of the base unchanged. When you run
their EKF (`robot_localization`, fusing wheel odom + `/imu/data`), set
`diff_drive_controller.enable_odom_tf: false` in `controllers.hw.yaml` so the
EKF owns the `odom → base_link` transform (otherwise two nodes publish it).
Standalone driving (no nav) keeps `enable_odom_tf: true`.

## Tower / arms

The deck-mounted mod101 arm (`base101_arm_*`) is **sim-only** for now. The Axon
firmware does expose `/motor_manager/arm_cmd` (ST3215 servos) for a future arm
bring-up.

The cross tower is parked out of the build in [`attic/`](attic/README.md) — its
deck mount no longer matches the re-exported chassis, and no real driver was
ever wired for its lift / pan / tilt.

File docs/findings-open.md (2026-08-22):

# Open findings — things noticed but not fixed

Written 2026-08-22 during the bringup restructure (see
`bringup-restructure.md`). None of these are caused by that restructure;
they were either already there or are environment gaps. Ordered by how
likely they are to bite.

## 1. Nav goal aborts with START_OCCUPIED on a cold map — UNVERIFIED

A `NavigateToPose` to (0.8, 0.0) on a freshly launched sim came back:

```
GridBased plugin failed to plan from (-0.00, -0.00) to (0.80, 0.00): "Start occupied"
NavigateToPose -> ABORTED, error_code 205   # ComputePathToPose START_OCCUPIED
```

The planner believes the robot's own start cell is lethal. `/map` and the
global costmap agreed on extent (297x163 @ 0.05 m, origin -7.43/-2.22), so
the goal was well inside bounds — this is about cost at the start cell, not
geometry.

**Why it is unverified:** a stale `gz sim` server from an earlier run was
still alive during this test, and immediately afterwards teleop failed to
move the robot at all (`map->base_link` stayed at 0,0), which is the
duplicate-server signature. So the result may be an artifact of two servers
fighting rather than a real planning failure. **Re-run on a clean sim before
spending time on it.**

If it does reproduce, the leads are:

- The `nav_restructure.md` bring-up test drove the robot around *before*
  goaling, so it never planned from a cold, mostly-unknown map. A cold start
  may simply mark the unexplored start cell lethal.
- The related warning below (#2) is emitted at the same time and is about
  exactly this: inflation not configured for the planner's collision checker.
- `planner_server` also logs `Robot is out of bounds of the costmap` once
  during activation, before the static layer resizes to the SLAM map. Benign
  on its own, but worth confirming it clears.

## 2. SmacPlanner2D warns the inflation layer is inadequate

Logged as ERROR on every single nav bringup, before any goal:

```
Inflation layer either not found or inflation is not set sufficiently for
optimized non-circular collision checking capabilities. It is HIGHLY
recommended to set the inflation radius to be at MINIMUM half of the robot's
largest cross-section.
```

`costmap.yaml` does configure an `inflation_layer` — so this is about the
radius being too small relative to the chassis, not a missing plugin. The
message claims a substantial run-time performance cost, and it may well be
the same root cause as #1. Worth one pass with the real chassis
cross-section.

## 3. No hardware path for the arm

`base101.hardware.xacro` emits a `ros2_control` block for the four wheel
joints only, and `controllers.hw.yaml` has no arm section. There is nothing
for an arm controller to claim on the real robot.

`base101_bringup_hw` therefore **raises on `arm:=true`** rather than coming
up half-working. Making it real needs, in order: a mod101 `SystemInterface`
(or a second `ROS2ControlBridge` instance) in the hardware xacro, then the
arm block mirrored from `controllers.sim.yaml`, then dropping the guard in
`robot.launch.py`.

## 4. MoveIt is not installed on this machine

`ros2 launch base101_arm_moveit_config move_group.launch.py` fails with
`ModuleNotFoundError: No module named 'moveit_configs_utils'`, and
`dpkg -l | grep ros-jazzy-moveit` returns nothing. The package builds fine
(it is ament_cmake installing configs) but cannot run here, so
`sim.launch.py moveit:=true` is untested on this box. Everything MoveIt-side
in the restructure — the SRDF robot-name fix and the URDF path change below —
is therefore **verified only by inspection, never executed**.

Note the restructure did change two things MoveIt depends on:

- `srdf/base101_arm.srdf.xacro`'s `<robot name>` went `base101_arm` ->
  `base101`, to match the merged URDF. A mismatch here makes MoveIt reject
  the semantic description outright.
- `move_group.launch.py` now builds from
  `base101_description/urdf/base101.xacro` with `arm:=true`.

Both need a real run on a machine with MoveIt before they can be trusted.

## 5. `base101_control/README.md` documents the wrong hardware interface

It says the real-hardware plugin is `mock_components/GenericSystem`, "replace
before flying". `base101.hardware.xacro` actually declares
`base101_control_plugin/ROS2ControlBridge` — the real Axon 2 firmware bridge
over zenoh. The README is stale, describing a placeholder that has since been
replaced. (`bringup-restructure.md` repeated the claim; corrected there.)

The deleted `control_stack.launch.py` carried the same stale note in its
docstring, so that copy is gone with it.

## 6. The robocore engine still points at the stale flagship profile

`engine/profiles/base101_full.yaml` describes chassis + cross tower + **dual**
mod101 arms — a robot that can no longer be built (tower parked in `attic/`,
dual-arm overlay gone). None of its topics resolve: `/tower_controller`,
`/left_arm_controller`, `/right_arm_controller`, `/head_camera/*`, and the
`controllers.arms.yaml` it cites as the source of its joint names.

It has been marked `STALE — DO NOT USE` at the top rather than deleted,
because these still name it and need retargeting to `base101_arm.yaml` first:

- `bpe/docker-compose.localhost.yaml` (the agent's `--profile` argument)
- `bpe/simulation.yaml`
- `engine/README.md` (two places), `engine/missions/README.md`,
  `engine/examples/README.md`, `engine/docs/course/README.md` and
  `engine/docs/course/build_notebooks.py`

Those live in the engine repo, outside this workspace, so they were left
alone.

## 7. `base101_nav/config/laser_filter.yaml` is orphaned

Nothing launches a `laser_filters` node — the package's own README already
admits "(not currently launched)". Either wire it into the nav stack or
delete the file; right now it reads as configuration that is doing something
when it is not.

## 8. SLAM and Nav disagree on `bond_timeout`

`base101_slam` sets `bond_timeout: 0.0` deliberately — `nav_restructure.md`
records that the bond heartbeat misfires under sim time and looped
slam_toolbox through deactivate/reactivate forever. `base101_nav` still uses
`30.0` and has not shown the problem. Fine as it stands, but if the nav
servers ever start flapping the same way, that is the knob, and the reason is
written down in `nav_restructure.md` rather than at the call site.

## 9. Cosmetic: SDF warnings and rosboard topic warnings

- Gazebo logs `XML Element[gz_frame_id] ... not defined in SDF` for all four
  sensors on every launch. Harmless (gz copies the element through), but it
  is four lines of noise at every startup.
- With `arm:=false`, rosboard repeatedly warns `topic
  /arm_wrist_camera/image_raw not found`. The topic list it subscribes to is
  not conditioned on the configuration. Noise only.

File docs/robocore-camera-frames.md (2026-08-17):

# Camera frames: what robocore-sdk needs to change

**Status:** the robot side is done. **The SDK side is not.** Until the profile
change below lands, `deproject`, `get_cloud` and anything built on them are
wrong by 90° for `base_camera` — silently, with no error.

---

## The change, in one line

In the robot profile, `base_camera` must be declared **`optical: true`**.

```yaml
cameras:
  base_camera:
    optical: true      # <- was false (or absent); must now be true
  arm_wrist_camera:
    optical: true      # <- if/when the wrist camera is added
```

---

## Why

Every camera has two coordinate conventions for the same physical lens:

| Frame | Axes | Used by |
|---|---|---|
| `camera_link` | x forward, y left, z up (REP-103 link) | the URDF; where you mount it |
| `camera_optical_frame` | **z forward**, x right, y down (REP-103 optical) | image / `camera_info` headers |

A point 1 m straight ahead is `(1, 0, 0)` in link axes and `(0, 0, 1)` in optical
axes. Same point, different numbers — so mixing them up rotates results by 90°
without any error.

The pinhole formula in `sensing.py` always produces **optical** coordinates:

```python
optical = np.array([(u - k.cx) * d / k.fx, (v - k.cy) * d / k.fy, d])
point   = optical if record.optical else _OPTICAL_TO_LINK @ optical
target  = in_frame or record.tf_frame      # tf_frame = message header frame_id
```

Note the last element is `d`, the depth — z is forward, by construction. So
`record.optical` must describe **the frame the message is stamped with**:

- stamped `camera_link` → `optical: false` → rotate to link axes, TF from `camera_link`
- stamped `camera_optical_frame` → `optical: true` → leave as-is, TF from the optical frame

Both are internally consistent. What breaks is a mismatch between the stamped
frame and the flag.

## What changed on the robot

`base_camera` used to stamp `camera_link`, paired with `optical: false`. That was
consistent, but it did not match the hardware.

It now stamps `camera_optical_frame`, because **that is what the real drivers
do**:

- **RealSense** — `realsense2_camera/src/base_realsense_node.cpp` sets both
  `_camera_info[stream_index].header.frame_id = OPTICAL_FRAME_ID(stream_index)`
  and `img_msg_ptr->header.frame_id = OPTICAL_FRAME_ID(stream)`. Never the link
  frame. Its docs: *"All data published in our wrapper topics is optical data
  taken directly from our camera sensors."*
- **OAK-D / depthai** — publishes `oak_*_camera_optical_frame` per sensor.
- **REP-103** — *"In the case of cameras, there is often a second frame defined
  with a `_optical` suffix. This uses a slightly different convention: z
  forward, x right, y down."*

So when a real D435 or OAK-D replaces the simulated module, the frame graph and
the stamped frames stay the same. Nothing in the SDK has to be re-taught, and
sim results match hardware results.

`arm_wrist_camera` was built this way from the start.

## Frames on the real hardware

The drivers publish a subtree, not a single frame:

```
camera_link                          <- the mount point in our URDF
├── camera_color_frame               <- per-sensor, link axes
│   └── camera_color_optical_frame   <- images + camera_info stamped here
└── camera_depth_frame
    └── camera_depth_optical_frame
```

Our sim collapses this to one `camera_optical_frame` shared by rgb and depth.
That is deliberate and matches the normal hardware setup: depth is aligned to
colour (`align_depth` on RealSense), which publishes depth **in the colour
optical frame** — the same shared-frame pairing `get_depth` / `get_synced` /
`deproject` / `get_cloud` already assume.

If you ever run unaligned depth, the two streams get different optical frames
and that assumption no longer holds.

## Checklist

- [ ] `base_camera` → `optical: true` in the profile
- [ ] `arm_wrist_camera` → `optical: true` when it is added to a profile
- [ ] Re-verify one `deproject` against a known target after the change
- [ ] Do **not** copy `optical: false` from any older profile

## How to verify

With the sim up:

```bash
ros2 topic echo --once /base_camera/camera_info --field header
# expect: frame_id: camera_optical_frame

ros2 run tf2_ros tf2_echo camera_link camera_optical_frame
# expect: translation [0,0,0], RPY [-1.571, 0.000, -1.571]
```

Then deproject a pixel on an object of known position. If the answer is right in
magnitude but rotated ~90°, the flag and the stamped frame disagree.

---

Robot-side references: `base101_description/urdf/chassis.gazebo` (sensor
definitions), `chassis.xacro:888` (the optical frame), and
`mod101_description/urdf/mod101.gazebo` for the wrist camera.

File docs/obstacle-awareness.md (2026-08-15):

# Obstacle awareness: where it belongs

Design note, not a worklog — nothing here is implemented yet. Written while
adding `base101_arm_moveit_config`, when the question "should we configure an
octomap sensor plugin?" turned out to be a layering question rather than a
config one.

## The tension

Perceiving obstacles is not the picking layer's job. But picking cannot plan a
safe motion without knowing where the obstacles are. So either the picking layer
grows a perception dependency it shouldn't have, or obstacle awareness lives
somewhere lower and picking inherits it.

The resolution below is that this is a false binary: there are **two different
kinds of obstacle** and they belong in two different layers. The seam is already
drawn by MoveIt's own API, which is a good sign it's the natural one.

## Where things actually stand

**MoveIt's planning scene contains the robot and nothing else.** As of
`base101_arm_moveit_config`, that means self-collision plus the arm-vs-chassis
matrix — the arm will not drive itself through its own lidar. It has no
representation of the world at all. The `[ERROR] No 3D sensor plugin(s) defined
for octomap updates` at move_group startup is exactly that, reported.

**There are already two unrelated obstacle representations in the stack**, and
an octomap would be a third:

| | source | dimensionality | consumer |
|---|---|---|---|
| Nav2 costmap | `/scan` (RPLidar C1, one plane at z=96.5 mm) | 2D | base motion |
| MoveIt planning scene | URDF/SRDF only | 3D, robot only | arm motion |
| *(proposed)* octomap | `/base_camera/depth_image` | 3D, world | arm motion |

They are not redundant. A 2D costmap slice at 96.5 mm cannot tell the arm
whether a table surface at 300 mm is in the way, and the octomap cannot tell the
base what is behind it. Do not try to unify them.

**The perception input exists and is bridged.** `/base_camera/depth_image`
(32FC1, 30 Hz) plus `/base_camera/camera_info`, from the RealSense D435 or the
OAK-D depending on `camera:=`. No point cloud is published anywhere, which is
fine: MoveIt's `DepthImageOctomapUpdater` takes the depth image directly.

**The geometry works out.** Camera at x=199, z=68 mm looking forward (87° HFOV,
71° VFOV); arm turret at z=186 mm with 525 mm reach. Measured overlap of what
the camera sees and what the arm can touch:

```
 range in front |  camera sees z  |  arm reaches z  | overlap
   x = 299 mm      -3 .. 140        -247 .. 619       -3 .. 140 mm
   x = 399 mm     -74 .. 211        -158 .. 530      -74 .. 211 mm
   x = 499 mm    -145 .. 282          17 .. 355       17 .. 282 mm
   x = 599 mm    -216 .. 353       out of reach       none
```

For the realistic case — something on the floor or a low table 300–500 mm ahead
— the camera sees it and the arm can reach it. This is worth doing.

## The split

**Unmodelled world → the robot layer, via octomap.** Furniture, walls, the edge
of the table, a person's arm. The robot does not know what these are and does
not need to; it needs to not hit them. This is a property of *the robot and its
sensors*, true regardless of what task is running, so it belongs with the robot
description / MoveIt config and every consumer inherits it for free. The picking
layer never mentions it.

**Known objects → the picking layer, via `CollisionObject`.** The thing being
picked, the bin it goes into, a fixture whose pose came from a detector. These
are *task* knowledge. The picking layer already has to model them — you cannot
grasp a thing you have no pose for — and MoveIt takes them through the planning
scene API. So picking pushes `CollisionObject`s and does not touch perception
plumbing.

**The handoff is `AttachedCollisionObject`.** At grasp, the target stops being
an obstacle and becomes part of the robot: attach it to `arm_wrist_flange` and
MoveIt stops planning collisions between it and the gripper while still avoiding
it against everything else. This is the one place the two layers must
cooperate, and it is a single API call, not a dependency.

So: picking depends on *the planning scene*, not on *perception*. That is the
answer to the tension. The picking layer says "avoid what you know about"; what
the robot knows about is assembled below it.

### The trap

The octomap and the task objects will fight if you are careless. The object
being picked is visible to the camera, so it lands in the octomap as occupied
voxels; then picking adds it *again* as a `CollisionObject`; then the gripper
tries to close on it and collides with the octomap copy of the thing it is
holding. MoveIt's answer is to exclude the region: when a `CollisionObject` is
added the octomap must be cleared where it sits, and an attached object masks
its own voxels. Plan for this from the start — it presents as "the grasp always
fails at the last 2 cm" and is very confusing if you haven't thought about it.

## Open decisions before implementing

1. **Which frame the depth image is stamped in.** `chassis.gazebo` currently
   sets `gz_frame_id` to `camera_link` (+X forward). MoveIt's depth updater
   assumes the REP-103 optical convention (+Z forward) — that's what
   `camera_optical_frame` exists for. Options:
   - re-stamp `/base_camera/depth_image` in `camera_optical_frame`; correct, but
     robocore's `deproject` / `get_cloud` already consume that topic and may be
     compensating for the current frame, so it's a change with reach outside
     this workspace;
   - give the octomap its own `depth_camera` sensor in `chassis.gazebo`, stamped
     optically, on a separate topic. Nothing downstream shifts, at the cost of a
     second sensor in the sim.

   This is the decision to make first; everything else is mechanical.

2. **Self-filtering.** Without it the robot sees its own arm and marks it
   occupied, then refuses to plan through a ghost of itself. MoveIt masks the
   robot using its collision geometry — now clean primitives, so this should
   work well, but it wants verifying rather than assuming.

3. **Resolution and decay.** Octomap resolution trades planning cost against
   fidelity; and the arm occludes the camera while it works, so voxels behind it
   go stale. Decide whether stale voxels are cleared aggressively (risk: the
   planner forgets a real obstacle) or conservatively (risk: phantom obstacles
   block the workspace).

4. **Where the picking layer lives at all.** It does not exist yet.
   `robocore_agent` reads arm joint state and explicitly marks itself
   "pre-MoveIt"; `base101_mcp` is a generic passthrough. Whatever gets built
   should depend on `moveit_ros_planning_interface` and the planning scene, not
   on camera topics.

## If you only do one thing

Configure the octomap updater against a correctly-framed depth topic and verify
self-filtering. That alone makes every future arm motion obstacle-aware without
the picking layer existing yet, and it is the piece that genuinely cannot live
in the picking layer.

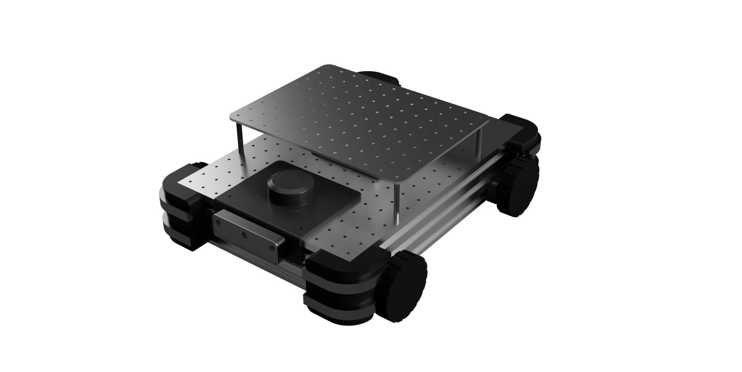
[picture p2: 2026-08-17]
img/top-ish.png

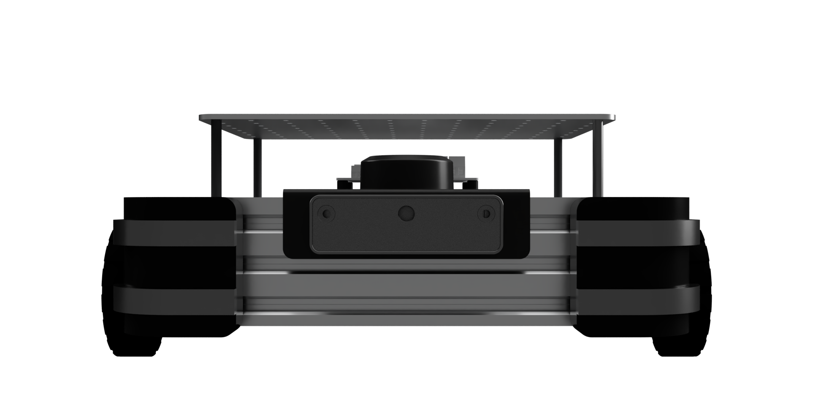
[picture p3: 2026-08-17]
img/front.png

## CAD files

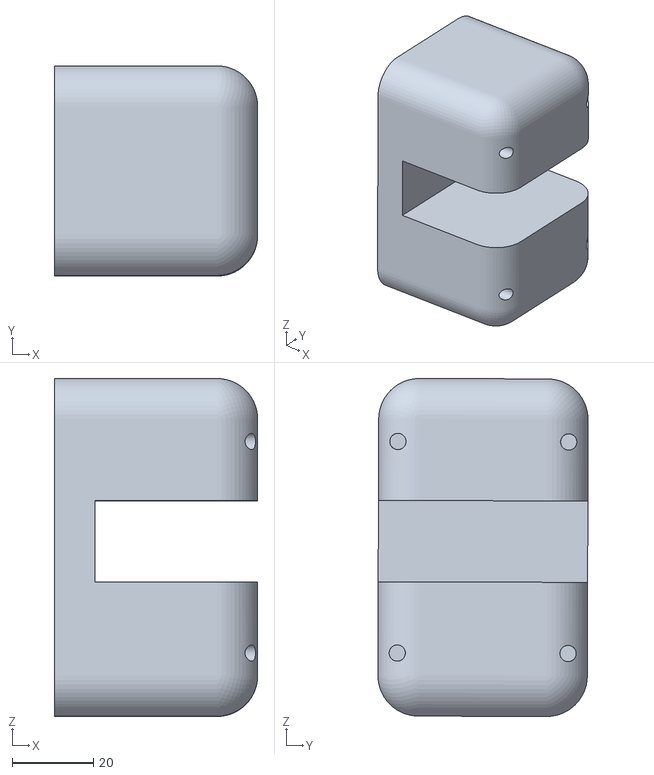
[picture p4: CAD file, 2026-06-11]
attic/base101_tower/base101_tower_description/meshes/tower/connector_1.stl
50.0 x 51.7 x 83.1

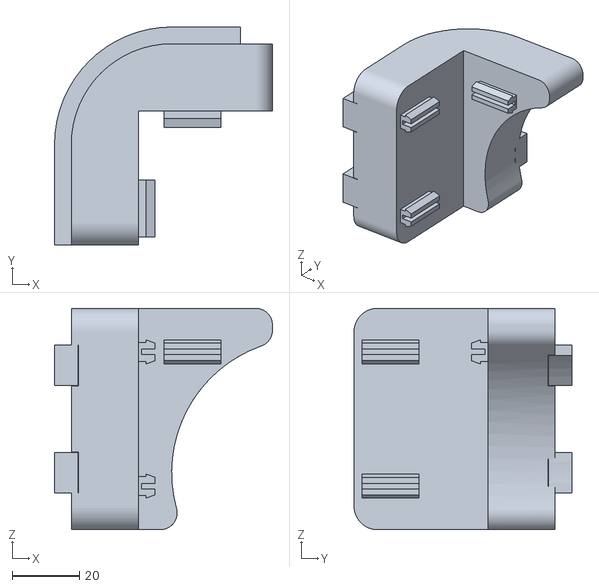
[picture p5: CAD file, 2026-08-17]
src/base101/base101_description/meshes/bumper_back_left_1.stl
65.0 x 65.0 x 66.0

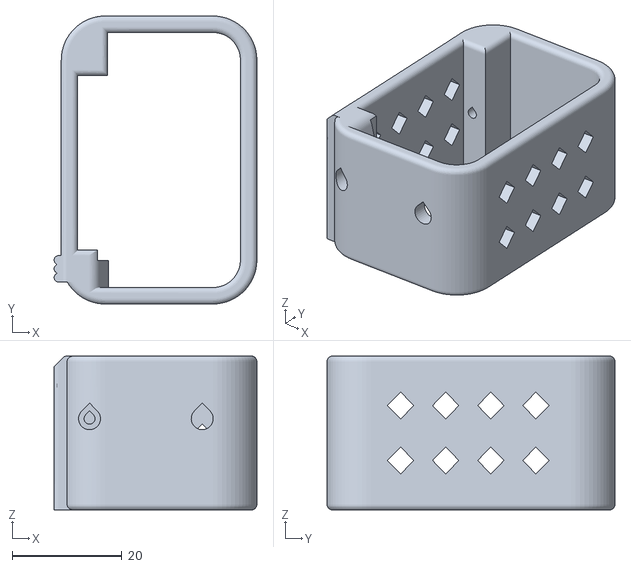
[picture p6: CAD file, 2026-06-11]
attic/base101_tower/base101_tower_description/meshes/tower/head_pan_thingy_1.stl
36.9 x 52.4 x 28.0

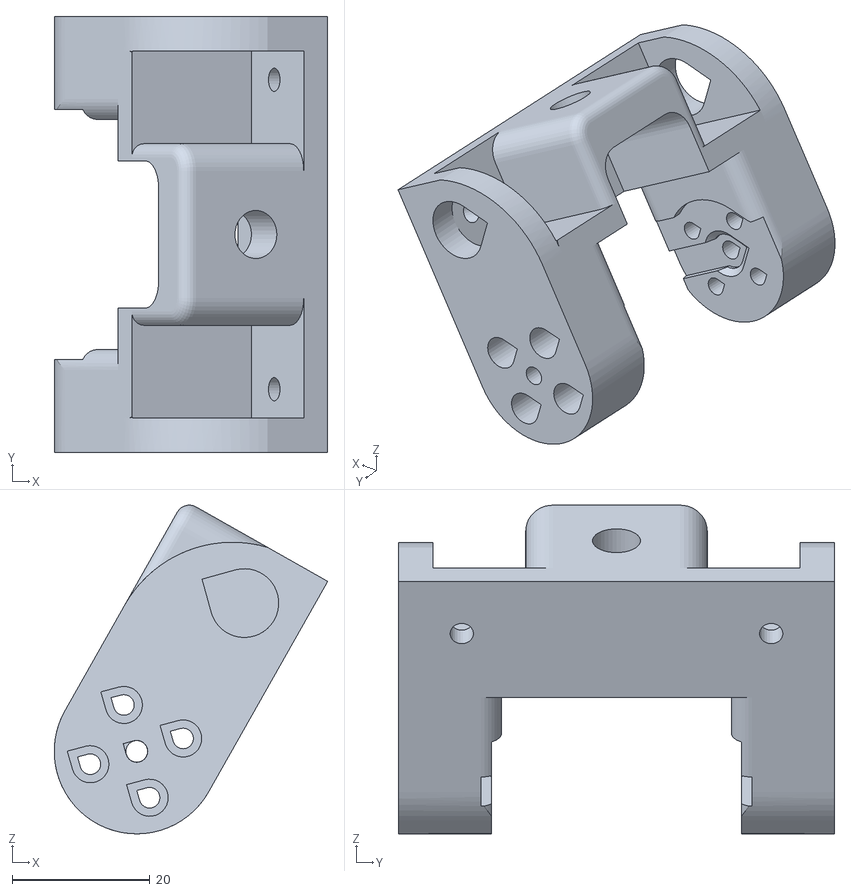
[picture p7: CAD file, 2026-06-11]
attic/base101_tower/base101_tower_description/meshes/tower/head_tilt_1.stl
39.8 x 63.4 x 47.8

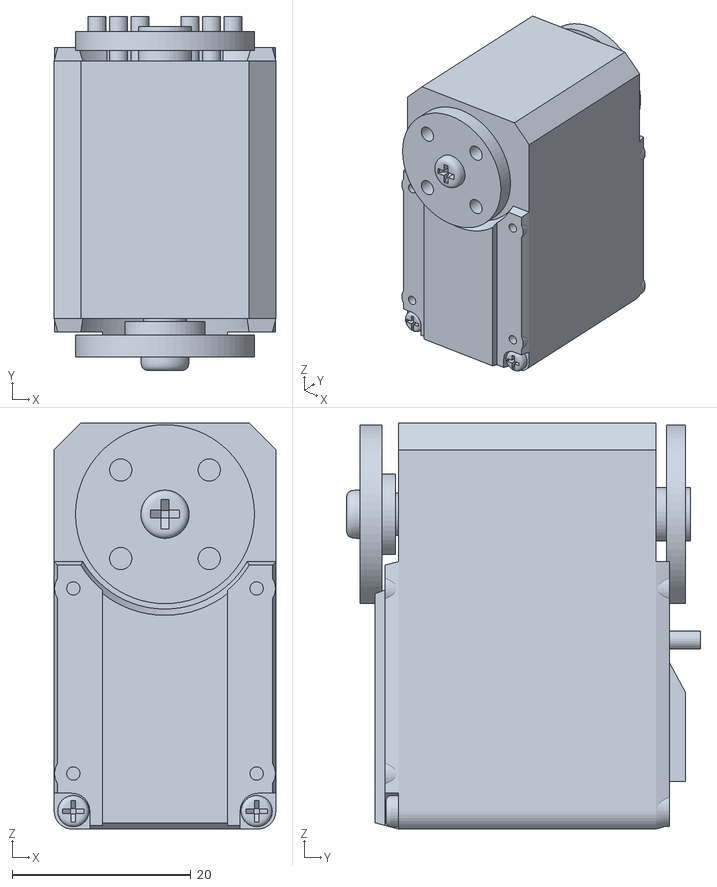
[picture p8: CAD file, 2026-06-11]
attic/base101_tower/base101_tower_description/meshes/tower/head_tilt_motor_1.stl
24.8 x 39.6 x 45.4

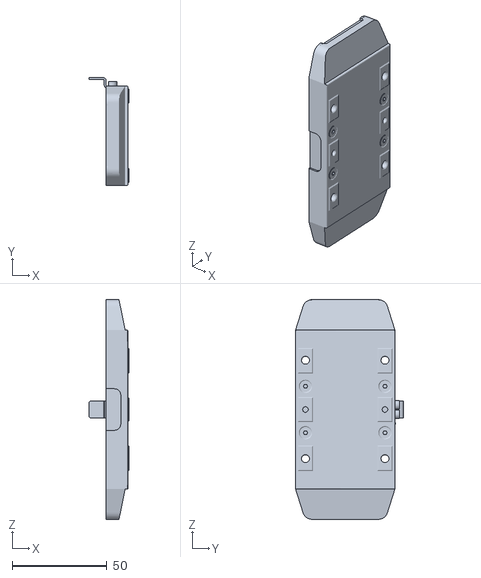
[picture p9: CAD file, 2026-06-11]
attic/base101_tower/base101_tower_description/meshes/tower/column_mount_1.stl
21.1 x 57.0 x 116.2

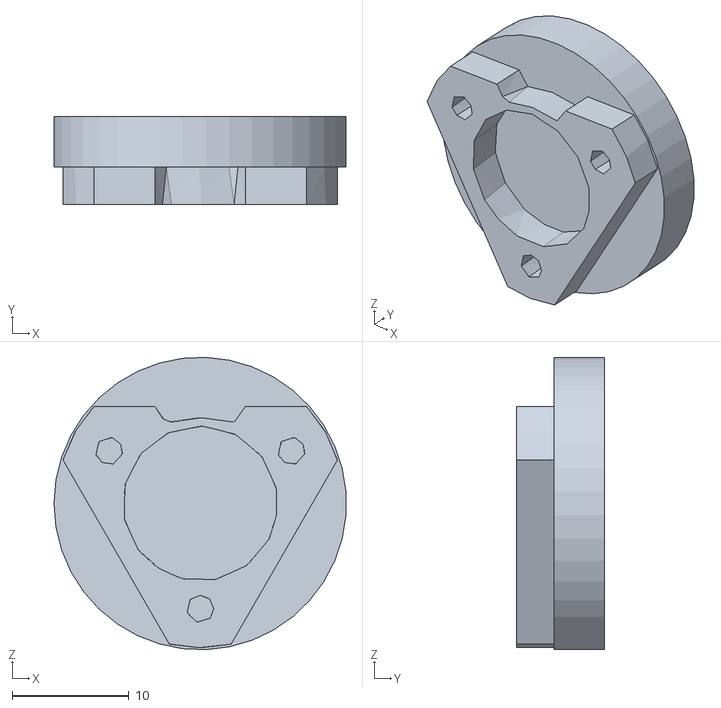
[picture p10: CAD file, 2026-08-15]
src/base101/base101_description/meshes/wheel_hub_front_left_1.stl
25.0 x 7.50 x 25.0

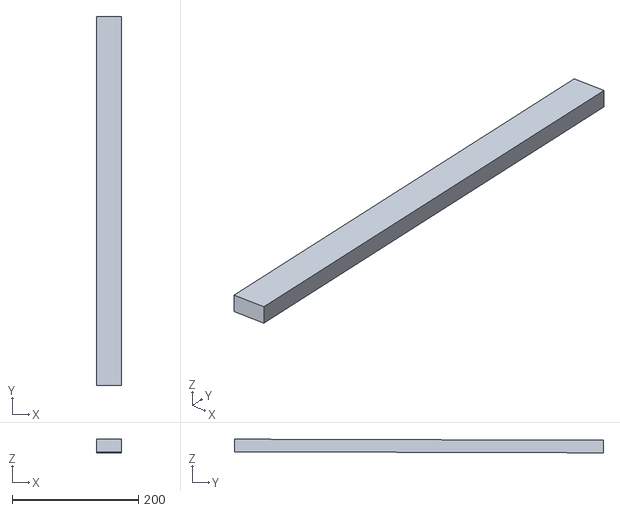
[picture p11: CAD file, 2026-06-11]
attic/base101_tower/base101_tower_description/meshes/tower/crossbeam_1.stl
40.0 x 584.2 x 21.7

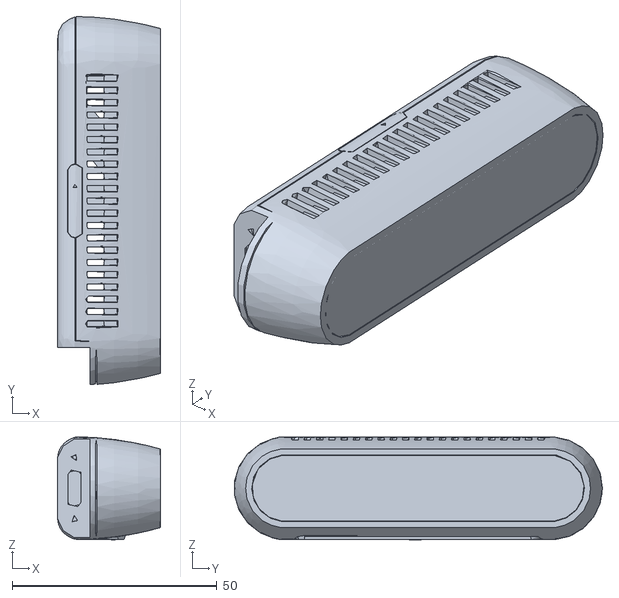
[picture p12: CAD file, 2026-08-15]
src/base101/base101_description/meshes/camera_realsense_1.stl
25.1 x 89.9 x 25.1

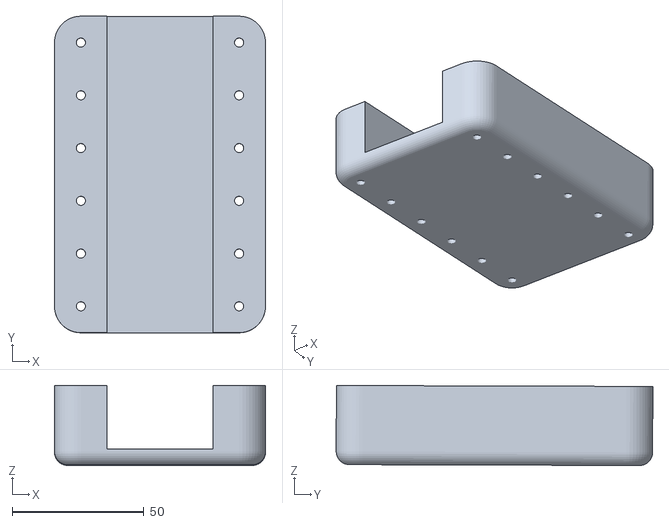
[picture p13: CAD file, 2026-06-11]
attic/base101_tower/base101_tower_description/meshes/tower/left_arm_bracket_1.stl
80.0 x 120.1 x 30.3

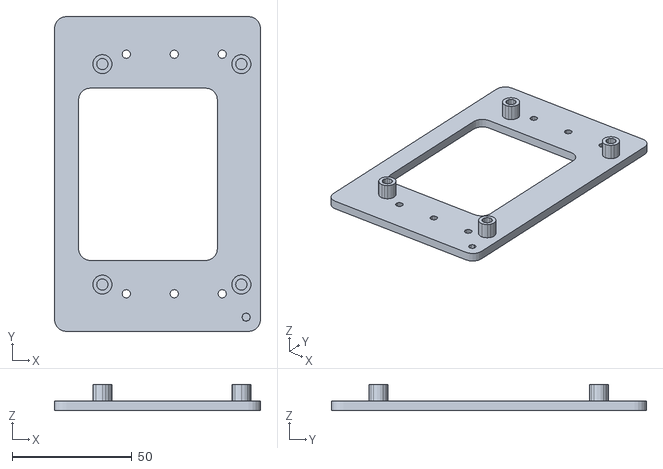
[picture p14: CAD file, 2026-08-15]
src/base101/base101_description/meshes/jetson_mount_1.stl
86.0 x 131.5 x 11.0

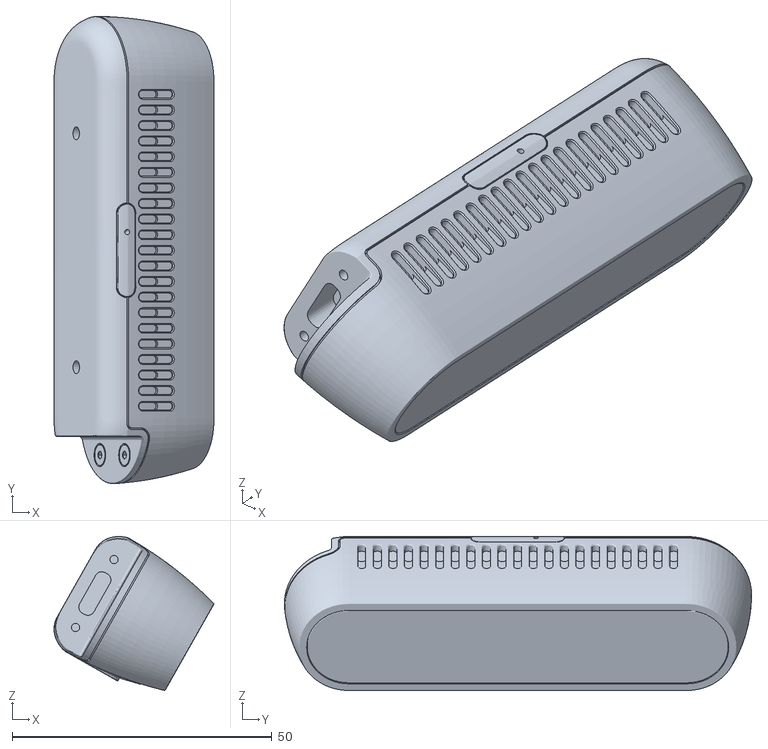
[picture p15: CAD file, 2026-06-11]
attic/base101_tower/base101_tower_description/meshes/tower/head_camera_1.stl
30.8 x 89.9 x 29.6

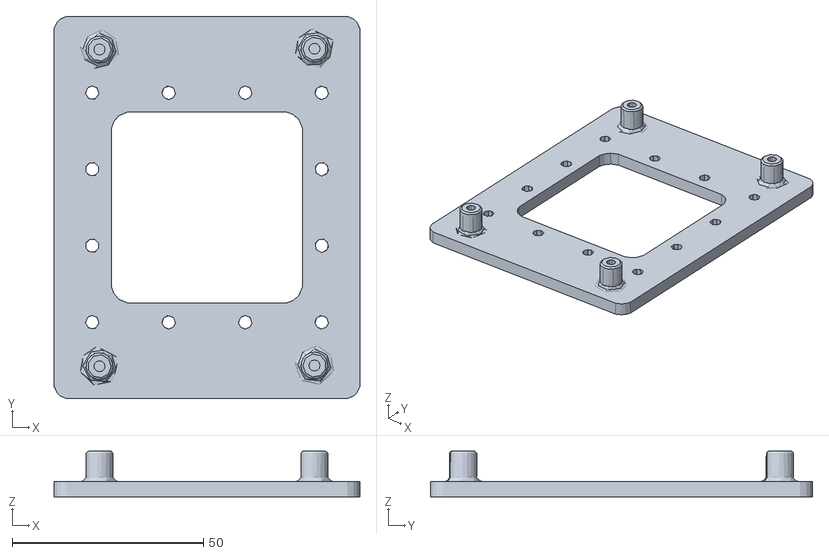
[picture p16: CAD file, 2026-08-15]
src/base101/base101_description/meshes/orp_link101_mount_1.stl
80.0 x 100.0 x 12.0

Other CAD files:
src/base101/base101_description/meshes/bumper_front_left_1.stl
src/base101/base101_description/meshes/bumper_front_right_1.stl
src/base101/base101_description/meshes/bumper_back_right_1.stl
attic/base101_tower/base101_tower_description/meshes/tower/head_pan_camera_1.stl
src/base101/base101_description/meshes/wheel_hub_back_left_1.stl
attic/base101_tower/base101_tower_description/meshes/tower/camera_support_1.stl
attic/base101_tower/base101_tower_description/meshes/tower/column_1.stl
attic/base101_tower/base101_tower_description/meshes/tower/head_pan_1.stl
attic/base101_tower/base101_tower_description/meshes/tower/right_arm_bracket_1.stl
src/base101/base101_description/meshes/base_link.stl
src/base101/base101_description/meshes/box_back_1.stl
src/base101/base101_description/meshes/box_front_1.stl
src/base101/base101_description/meshes/box_left_1.stl
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

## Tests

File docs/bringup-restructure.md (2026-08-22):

# base101 package restructure — two bringup packages

Proposal, 2026-08-22. Replaces the `simple`/`arm` package split with one
model + one config set + two launch owners.

## Why

The `simple` vs `arm` distinction is one boolean, currently expressed as
six packages across three axes:

| axis | simple | arm |
|---|---|---|
| description | `base101_simple_description` | `base101_arm_description` |
| control | `base101_simple_control` | `base101_arm_control` |
| gazebo | `base101_simple_gazebo` | `base101_arm_gazebo` |

The two top-level xacros differ by **two lines** (one `<xacro:include>` of
the arm, one path in the gz_ros2_control `<parameters>` tag). The two
gazebo launches are ~220 lines each and ~90% identical — bridges, twist_mux,
rosboard, spawner event chains, all copy-pasted. Wiring nav in today meant
writing the same 30-line block twice, which is what prompted this.

## Target layout

Three layers, and only the launch layer is typed by a human.

### Model — what the robot is

```
base101_description/
  urdf/base101.xacro          <- THE robot. args: arm, arm_tool, camera, simulator
  urdf/chassis.xacro          (unchanged)
  urdf/chassis.{gazebo,gazebo.ros2control,mujoco.ros2control}
  urdf/arm.xacro              <- moved from base101_arm_description
  urdf/materials.xacro
  meshes/                     (unchanged)
base101_control_plugin/       (unchanged — C++ SystemInterface)
```

`base101.xacro` absorbs both variant xacros:

```xml
<xacro:arg name="arm" default="false"/>
<xacro:if value="$(arg arm)">
  <xacro:include filename="$(find base101_description)/urdf/arm.xacro"/>
</xacro:if>
```

**The one risk to verify first:** `arm.xacro` pulls in `mod101_description`,
so folding it into `base101_description` threatens armless builds that have
no mod101 underlay. xacro skips `<xacro:include>` inside a false
`<xacro:if>`, so `arm:=false` should never resolve `$(find mod101_*)` — but
this needs a real test (build in a container without mod101) before the
merge is committed. If it fails, the fallback is to keep
`base101_arm_description` as the single remaining `*_arm` package and have
`base101.xacro` include from it conditionally; everything else below is
unaffected.

### Config — how it's tuned

```
base101_control/
  config/controllers.sim.yaml   <- wheels + arm + trajectory variants, merged
  config/controllers.hw.yaml    <- same, for the real robot
  config/twist_mux.yaml
  urdf/base101.hardware.xacro   <- moved from base101_simple_control
base101_nav/     config/ + behavior_trees/ + launch/nav.launch.py
base101_slam/    config/ + maps/ + launch/slam.launch.py
base101_worlds/  worlds/ + config/gz_ros_bridge.yaml   <- renamed from base101_gazebo
base101_arm_moveit_config/                             <- unchanged
```

Merging the controller yamls is safe: the arm controllers are *declared*
in `controller_manager.ros__parameters` but only **spawned** by name, so an
armless robot simply never spawns them. `base101_worlds` gets renamed off
`base101_gazebo` because `base101_gazebo` vs `base101_bringup_gazebo`
side-by-side is a coin flip every time you read it.

### Launch — the two packages you actually type

```
base101_bringup_gazebo/launch/sim.launch.py
base101_bringup_hw/launch/robot.launch.py
```

Both own the **whole** graph and expose the same argument contract, so
muscle memory transfers between sim and robot:

| arg | default | meaning |
|---|---|---|
| `arm` | `false` | mount one mod101 arm |
| `arm_tool` | configurator's | mod101 end-effector |
| `arm_control` | `sliders` | `sliders` (position) or `moveit` (trajectory) |
| `nav` | `true` | Nav2 |
| `slam` | `true` | EKF + slam_toolbox |
| `rviz` | `false` | nav display config |
| `rosboard` | `true` | web dashboard |
| `moveit` | `false` | move_group (implies `arm_control:=moveit`) |
| `agent` | `true` | robocore agent (JSON-RPC bridge) |
| `profile` | auto | robocore profile YAML; auto-picked by `arm` |
| `world` | `sticky_floor.sdf` | **sim only** |
| `camera` | `realsense` | **sim only** (hw reads what's plugged in) |

### What stays composable

`base101_nav` and `base101_slam` **keep** their launch files. They are the
stack definitions; the bringup packages compose them via
`IncludeLaunchDescription`. This preserves the independence ruling from
`nav_restructure.md` — `ros2 launch base101_nav nav.launch.py` still works
standalone for debugging, and neither stack knows about the other. The rule
is narrower than "bringup owns all launch":

> **The bringup packages own every *top-level* launch — the ones a human
> types. Stack packages may own a stack launch, which only bringup includes.**

`base101_arm_moveit_config` is left alone; it is
moveit_setup_assistant-shaped and regenerating it is not worth the fight.

### Deleted

`base101_simple_description`, `base101_simple_control`,
`base101_simple_gazebo`, `base101_arm_control`, `base101_arm_gazebo`, and
`base101_arm_description` (the xacro test above passed — see Outcome). Their
`display.launch.py` files collapse into one
`base101_bringup_hw/launch/display.launch.py` with the same `arm` arg.

Net: 14 packages -> 9.

## Migration order

Each step leaves the tree buildable and the sim launchable.

1. **`base101_worlds` rename.** Mechanical, no behaviour change. Do it first
   so later steps write the final name.
2. **Merge the xacros** into `base101_description/urdf/base101.xacro`, with
   the armless-build test. Old variant xacros stay as two-line shims that
   include the new one, so nothing breaks yet.
3. **Merge the controller yamls** into `base101_control`.
4. **Write `base101_bringup_gazebo`** as the union of the two gazebo
   launches — one `arm` branch instead of two files. Verify against both
   `arm:=false` and `arm:=true`.
5. **Write `base101_bringup_hw`** from `control_stack.launch.py` + the
   autonomy includes.
6. **Delete the six packages** and the shims; update `README.md`,
   `docs/testing.md`, and the robocore profiles that name launch files.

Steps 1–3 are safe to land independently of whether 4–6 ever happen.

## Gaps this surfaces (not caused by it)

Moved to `findings-open.md`, which is the live list. In summary: no hardware
path for the arm, a cold-map `START_OCCUPIED` nav abort that still needs
confirming, an inflation-radius warning on every nav bringup, MoveIt not
installed on this machine, an orphaned `laser_filter.yaml`, and a
`bond_timeout` disagreement between the two stacks.

One item from the original draft was **wrong** and is corrected there: the
hardware control stack is *not* mock. `base101.hardware.xacro` declares
`base101_control_plugin/ROS2ControlBridge`, the real Axon 2 bridge. It was
`base101_control/README.md` that still described a
`mock_components/GenericSystem` placeholder, and this document repeated it.

## Outcome

Landed 2026-08-22, all six steps. Deviations from the plan above:

- **The armless-build risk did not materialise.** `arm:=false` processes
  with the mod101 underlay stripped from `AMENT_PREFIX_PATH` entirely (38
  links), and `arm:=true` without it fails cleanly pointing at `arm.xacro`.
  So `base101_arm_description` was deleted rather than kept as the fallback.
- **`base101_arm_moveit_config/launch/demo.launch.py` was deleted too.** It
  was a top-level launch (it included the gazebo launch and then move_group),
  which is exactly what the ownership rule says bringup owns. Its job is now
  `sim.launch.py arm:=true moveit:=true`. `move_group.launch.py` stays as the
  stack launch.
- **The SRDF's `<robot name>` had to change** from `base101_arm` to
  `base101` to match the merged URDF's robot name. Unverified — see
  `findings-open.md` #4.
- The two `display.launch.py` files collapsed into
  `base101_bringup_hw/launch/display.launch.py` as planned.
- **`robocore_agent` was added to both bringups** (`agent:=true` by default),
  which the original plan did not cover — it had been run by hand. Its
  profile is resolved from the engine repo rather than copied into this
  workspace, because docker-compose, `simulation.yaml` and the course
  notebooks all reference `engine/profiles/` and a copy would drift.

Verified on a clean sim: `sim.launch.py` with no arguments brings up Gazebo,
both controllers, `/clock` at ~300 Hz, and all five lifecycle nodes
(`planner_server`, `controller_server`, `bt_navigator`, `velocity_smoother`,
`slam_toolbox`) reach `active` with `map->odom` publishing. Full `colcon
build` clean; every remaining launch file parses except `move_group.launch.py`,
which needs MoveIt installed.

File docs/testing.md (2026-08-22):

# Manual test guide

Every combination this robot ships, how to launch it, and what a pass looks
like. Written to be worked through top to bottom after a change that touches the
description, the controllers, MoveIt, or the mod101 integration.

Section 1 is offline and takes seconds — run it first, it catches most
breakage. Sections 2-6 need a sim. Section 7 is the independence check that
must pass before you ship anything that touched mod101.

## 0. Build

mod101 is an **underlay**: build and source it first, always. Full rules and the
reason for the `Python3_EXECUTABLE` pin are in the
[README's Build section](../README.md#build) — this is the same thing, in one
paste:

```bash
source /opt/ros/jazzy/setup.bash

cd ~/robots/mod101 && colcon build --symlink-install && source install/setup.bash
cd ~/robots/base101
colcon build --symlink-install --cmake-args -DPython3_EXECUTABLE=/usr/bin/python3
source install/setup.bash
```

Expect 8 packages in mod101 and 15 in base101. `base101_control_plugin`
produces stderr output during build; that is pre-existing and not a failure.

If you changed a mesh or deleted a file, `--symlink-install` will trip over the
stale symlink. Clear the one package:

```bash
rm -rf build/<pkg> install/<pkg> && colcon build --symlink-install
```

## 1. Offline checks (no sim, ~30 s)

This is the gate. Everything here is pure xacro expansion, so it catches
malformed XML, missing meshes, renamed joints, broken args, and SRDF/URDF
disagreement without waiting for Gazebo.

```bash
cd ~/robots/base101
source /opt/ros/jazzy/setup.bash
source ~/robots/mod101/install/setup.bash
source install/setup.bash

# --- armless: 2 cameras x 3 simulators
for cam in realsense oak_d; do for sim in none gazebo mujoco; do
  xacro src/base101/base101_description/urdf/base101.xacro \
        simulator:=$sim camera:=$cam arm:=false >/dev/null \
    && printf "ok bare/%s/%s  " $sim $cam || printf "FAIL bare/%s/%s  " $sim $cam
done; done; echo

# --- with arm: 4 tools x 2 simulators
for tool in jaws parallel none pincopen; do for sim in none gazebo; do
  xacro src/base101/base101_description/urdf/base101.xacro \
        simulator:=$sim arm:=true arm_tool:=$tool >/dev/null \
    && printf "ok arm/%s/%s  " $sim $tool || printf "FAIL arm/%s/%s  " $sim $tool
done; done; echo

# --- armless must NOT need the mod101 underlay (regression guard: the arm
#     include lives inside a <xacro:if>, and must never be lifted out of it)
env AMENT_PREFIX_PATH="$(python3 -c "import os;print(':'.join(p for p in os.environ['AMENT_PREFIX_PATH'].split(':') if 'mod101' not in p))")" \
  xacro src/base101/base101_description/urdf/base101.xacro \
        simulator:=gazebo arm:=false >/dev/null \
  && echo "ok bare-without-mod101" || echo "FAIL bare-without-mod101"

# --- MoveIt semantics: 4 tools
for tool in jaws parallel none pincopen; do
  xacro src/base101_arm/base101_arm_moveit_config/srdf/base101_arm.srdf.xacro \
        arm_tool:=$tool >/dev/null \
    && printf "ok srdf/%s  " $tool || printf "FAIL srdf/%s  " $tool
done; echo

# --- every launch file resolves its args
for l in "base101_bringup_gazebo sim.launch.py" \
         "base101_bringup_hw robot.launch.py" \
         "base101_bringup_hw display.launch.py" \
         "base101_nav nav.launch.py" \
         "base101_slam slam.launch.py" \
         "base101_arm_moveit_config move_group.launch.py"; do
  printf "%-52s " "$l"
  timeout 90 ros2 launch $l --show-args >/dev/null 2>&1 && echo ok || echo FAIL
done

# --- kinematic tree is sane
xacro src/base101/base101_description/urdf/base101.xacro \
      simulator:=gazebo arm:=true > /tmp/base101_arm.urdf
check_urdf /tmp/base101_arm.urdf | head -3
```

**Pass:** every line `ok`, and `check_urdf` reports
`root Link: base_link has 16 child(ren)`.

### 1b. Controller/URDF agreement

The failure this catches is silent at expansion time and fatal at runtime: a
controller naming a joint that doesn't exist just fails to activate, and the arm
doesn't move with no obvious error.

```bash
python3 - <<'EOF'
import xml.etree.ElementTree as ET, yaml
r = ET.parse('/tmp/base101_arm.urdf').getroot()
joints = {j.get('name') for j in r.findall('joint')}
rcj = {j.get('name') for rc in r.findall('ros2_control') for j in rc.findall('joint')}
y = yaml.safe_load(open('src/base101/base101_control/config/controllers.sim.yaml'))
for n, c in y.items():
    if n == 'controller_manager': continue
    pr = c.get('ros__parameters', {})
    js = (pr.get('joints') or []) + pr.get('left_wheel_names', []) + pr.get('right_wheel_names', [])
    bad = [j for j in js if j not in joints or j not in rcj]
    print(f"  {n:30s} {'OK' if not bad else 'BAD ' + str(bad)}")
EOF
```

**Pass:** all six controllers `OK`.

## 2. Simple variant

```bash
ros2 launch base101_bringup_gazebo sim.launch.py
```

| check | how | pass |
|---|---|---|
| model spawns | Gazebo window | chassis on wheels, black plastics, dark-grey extrusion, lidar at the front |
| controllers | `ros2 control list_controllers` | `joint_state_broadcaster`, `diff_drive_controller` both `active` |
| driving | rosboard `http://localhost:8888/` Teleop card, or `ros2 topic pub /cmd_vel_key geometry_msgs/msg/Twist "{linear: {x: 0.2}}"` | robot drives forward, doesn't spin or crab |
| lidar | `ros2 topic hz /scan` | ~10 Hz |
| camera | `ros2 topic hz /base_camera/image_raw` and `/base_camera/depth_image` | ~30 Hz each |
| IMU | `ros2 topic hz /sensors/imu` | ~100 Hz |
| frames | `ros2 run tf2_tools view_frames` | `base_link` root; `lidar_frame`, `camera_link`, `camera_optical_frame`, `imu_link` present |

Camera toggle — the mesh and the simulated FOV change, the topics do not:

```bash
ros2 launch base101_bringup_gazebo sim.launch.py camera:=oak_d
```

**Pass:** the front module is visibly shorter, `/base_camera/*` topics are
identical, and `camera_link` still exists.

RViz only, no sim:

```bash
ros2 launch base101_bringup_hw display.launch.py                     # joint sliders GUI
ros2 launch base101_bringup_hw display.launch.py gui:=false camera:=oak_d
```

## 3. Arm variant — slider control

```bash
ros2 launch base101_bringup_gazebo sim.launch.py arm:=true
```

| check | how | pass |
|---|---|---|
| arm mounted | Gazebo | arm base flat on the deck, centred, not floating |
| controllers | `ros2 control list_controllers` | `arm_controller` and `gripper_controller` `active`; the `*_trajectory_controller` pair NOT loaded |
| rosboard sliders | `http://localhost:8888/` → "Joint sliders" | an **arm** group of 5 and a **gripper** group of 1 render; tower groups do not |
| teleop sliders | `http://localhost:8700/` | same groups |
| motion | drag a slider | the corresponding joint moves in Gazebo |
| wrist camera | `ros2 topic hz /arm_wrist_camera/image_raw` | publishing |

Direct command, bypassing the UIs:

```bash
ros2 topic pub --once /arm_controller/commands std_msgs/msg/Float64MultiArray \
  "{data: [0.0, 1.2, 1.5, 0.3, 0.0]}"     # the SRDF 'ready' pose
ros2 topic pub --once /gripper_controller/commands std_msgs/msg/Float64MultiArray \
  "{data: [2.0]}"                          # jaws open
```

Every tool:

```bash
for t in jaws parallel pincopen none; do
  ros2 launch base101_bringup_gazebo sim.launch.py arm:=true arm_tool:=$t
done
```

**Pass:** each end-effector appears; `gripper_controller` is absent for
`none`; on `parallel` and `pincopen` the extra jaw joints mimic `arm_6`, so one
command moves the whole gripper.

## 4. Arm variant — MoveIt planning

```bash
ros2 launch base101_bringup_gazebo sim.launch.py arm:=true moveit:=true
```

That is Gazebo with the trajectory controllers plus `move_group`, in order
(`moveit:=true` forces `arm_control:=moveit`). To drive a sim you already have
up, in two terminals:

```bash
ros2 launch base101_bringup_gazebo sim.launch.py arm:=true arm_control:=moveit
ros2 launch base101_arm_moveit_config move_group.launch.py
```

| check | how | pass |
|---|---|---|
| controllers swapped | `ros2 control list_controllers` | `arm_trajectory_controller`, `gripper_trajectory_controller` `active`; the position pair NOT loaded |
| actions offered | `ros2 action list \| grep follow_joint_trajectory` | two actions |
| move_group up | its console | `Successfully loaded planner 'OMPL'`, `Added FollowJointTrajectory controller for arm_trajectory_controller` ×2, then **`You can start planning now!`** |
| groups | RViz MotionPlanning → Planning Group | `arm_arm` and `arm_gripper` |
| named states | Goal State dropdown | `home`, `ready` on the arm; `open`, `closed` on the gripper |
| plan | `home` → `ready`, Plan | a trajectory is found in well under a second |
| execute | Plan & Execute | the arm follows it in Gazebo |

The only expected error at startup is
`No 3D sensor plugin(s) defined for octomap updates` — there is deliberately no
perception in the planning scene (see
[obstacle-awareness.md](obstacle-awareness.md)).

### 4b. The collision test that matters

This is the whole reason `base101_arm_moveit_config` exists, so test it
explicitly rather than assuming.

In RViz, drag the interactive marker to put the gripper **inside the lidar** —
low and forward, around `x = 0.14, y = 0.0, z = 0.10` in `base_link`. Then Plan.

**Pass:** the goal state shows in collision (the arm renders red) and planning
fails, or the planner routes around. **Fail:** it plans a straight line through
the lidar — which means the collision matrix over-disabled, and you should
regenerate with more trials (section 5c).

Also worth checking the inverse, that it is not *over*-constrained: `home` →
`ready` must still plan. If everything fails to plan, the matrix is
under-disabled and adjacent links are reporting permanent collision.

### 4c. Automated smoke test

mod101 ships `test/moveit_smoke.py` (FK → IK → impossible-IK → joint-space
plan). It hardcodes the unprefixed group and joint names, so against base101 it
needs `arm_arm` / `arm_joint_*` / `arm_wrist_flange`. Run the mod101 original
against mod101, and adapt it if you want the same gate here.

## 5. Configurator round-trip

The configurator is the source of truth for the arm's build: rail lengths,
servo mounts, and tool. base101 reads the same file, so a change must reach
both.

```bash
cd ~/robots/mod101
python3 configurator/server.py          # http://localhost:8000/
```

The configurator regenerates **mod101's** matrices only. base101's are this
workspace's responsibility — see 5b.

### 5a. It propagates

Set shoulder 0.21 m / elbow 0.19 m, pick a big shoulder motor, pick the parallel
tool, Save. Then:

```bash
grep default= ~/robots/mod101/src/mod101_description/urdf/mod101_config.xacro
```

**Pass:** `shoulder_ext_length="0.2100"`, `elbow_ext_length="0.1900"`,
`shoulder_mount="big"`, `tool="parallel"`.

Rebuild both workspaces, then confirm both robots changed together:

```bash
xacro ~/robots/mod101/src/mod101_description/urdf/mod101.xacro | grep -m1 'box size="0.21'
xacro src/base101/base101_description/urdf/base101.xacro \
      simulator:=none arm:=true | grep -m1 'box size="0.21'
```

**Pass:** both match. **Fail:** base101 shows 0.082/0.098 — the macro's own
defaults — meaning `arm.xacro` stopped passing the build args through.

The launch defaults follow too:

```bash
ros2 launch base101_bringup_gazebo sim.launch.py --show-args | grep -A2 "'arm_tool'"
```

**Pass:** `(default: 'parallel')`.

### 5b. It regenerates the collision matrices

Saving kicks a background regeneration of **mod101's** matrices. Watch the
configurator console for `[collisions] mod101: regenerated`, or poll:

```bash
curl -s localhost:8000/collisions
```

The same response carries a `downstream` note reminding you that consumers
regenerate themselves. Do that now, from this workspace:

```bash
./src/base101_arm/base101_arm_moveit_config/scripts/sync_arm_change.sh
```

**Pass:** it prints the mod101 underlay it resolved, then a per-tool pair count.
**Fail:** `mod101 underlay not built` — build mod101, or set `MOD101_WS`.

Then check the stamps:

```bash
grep -m1 shoulder_ext_length \
  ~/robots/mod101/src/mod101_moveit_config/config/collisions/jaws.srdf.xacro
grep -m1 shoulder_ext_length \
  src/base101_arm/base101_arm_moveit_config/config/collisions/jaws.srdf.xacro
```

**Pass:** both headers carry the values you just saved. A stale stamp means the
matrix no longer describes the arm you are planning for.

### 5c. Regenerating by hand

```bash
# base101 (chassis pairs) — all four tools, minutes at the 1M default
python3 src/base101_arm/base101_arm_moveit_config/scripts/gen_collision_matrix.py

# mod101 (arm-internal pairs)
python3 ~/robots/mod101/tools/gen_collision_matrix.py --trials 1000000
```

If you increased the arm's reach, re-run with more trials and diff — "never
colliding" is a sampling result, not a proof:

```bash
cp src/base101_arm/base101_arm_moveit_config/config/collisions/jaws.srdf.xacro /tmp/before
python3 src/base101_arm/base101_arm_moveit_config/scripts/gen_collision_matrix.py \
        --tool jaws --trials 4000000
diff <(grep -o 'link1="[^"]*" link2="[^"]*"' /tmp/before) \
     <(grep -o 'link1="[^"]*" link2="[^"]*"' \
       src/base101_arm/base101_arm_moveit_config/config/collisions/jaws.srdf.xacro)
```

Lines only in `/tmp/before` are pairs the lower trial count wrongly disabled.
Expect a handful; if it's dozens, the default needs raising.

## 6. Real hardware (armless only)

The arm is sim-only: `controllers.hw.yaml` has no arm section and
`base101.hardware.xacro` emits a `ros2_control` block for the wheels only, so
`robot.launch.py` refuses `arm:=true` outright. See
[findings-open.md](findings-open.md) #3.

```bash
export RMW_IMPLEMENTATION=rmw_zenoh_cpp
ros2 launch base101_bringup_hw robot.launch.py
ros2 launch base101_bringup_hw robot.launch.py nav:=false   # wheels only
```

See [HARDWARE.md](../HARDWARE.md). Note `controllers.hw.yaml` carries its own
`wheel_separation` (hardware-calibrated, deliberately not the URDF value).

## 7. mod101 independence

**Run this before shipping anything that touched mod101.** base101 is a
downstream consumer; mod101 must not have acquired a dependency on it.

```bash
env -i HOME=$HOME USER=$USER PATH=/usr/bin:/bin bash -lc '
source /opt/ros/jazzy/setup.bash
source ~/robots/mod101/install/setup.bash

echo "base101 entries on the path: $(echo $AMENT_PREFIX_PATH | tr : "\n" | grep -c base101)"

for t in jaws parallel none pincopen; do for m in small big; do
  xacro ~/robots/mod101/src/mod101_description/urdf/mod101.xacro \
        tool:=$t shoulder_mount:=$m elbow_mount:=$m >/dev/null \
    && printf "ok urdf/%s/%s " $t $m || printf "FAIL urdf/%s/%s " $t $m
done; done; echo

for t in jaws parallel none pincopen; do
  xacro ~/robots/mod101/src/mod101_moveit_config/srdf/mod101.srdf.xacro tool:=$t >/dev/null \
    && printf "ok srdf/%s " $t || printf "FAIL srdf/%s " $t
done; echo

for f in move_group mock demo; do
  timeout 60 ros2 launch mod101_moveit_config $f.launch.py --show-args >/dev/null 2>&1 \
    && printf "ok launch/%s " $f || printf "FAIL launch/%s " $f
done; echo
'
```

**Pass:** `base101 entries on the path: 0` and every check `ok`.

Also confirm the configurator works with no base101:

```bash
python3 -c "
import importlib.util
s = importlib.util.spec_from_file_location('c', '$HOME/robots/mod101/configurator/server.py')
m = importlib.util.module_from_spec(s); s.loader.exec_module(m)
print('targets:', [l for l,_,_ in m._regen_targets()])
print('downstream note:', bool(m.DOWNSTREAM_NOTE))"
```

**Pass:** `targets: ['mod101']` and `downstream note: True`.

This is now an invariant rather than a configuration: the configurator has no
consumer-workspace setting at all, so there is nothing to unset. If a second
label ever appears in `targets`, the dependency has been inverted again.

And the standalone MoveIt bringup still plans:

```bash
ros2 launch mod101_moveit_config mock.launch.py rviz:=false
python3 $(ros2 pkg prefix --share mod101_moveit_config)/test/moveit_smoke.py
```

## 8. Reference values

Compare against these when something looks off. All measured at
140/140 mm rails, small mounts, jaws.

| quantity | value |
|---|---|
| ground clearance to `base_link` | 0 mm (`base_link` is on the wheel contact plane) |
| extrusion frame | z 22–82 mm |
| base deck (`base_link` mesh) | 340 × 240 × 3 mm, z 82–85 |
| payload deck (`top_plate_1`) | 180 × 240 × 3 mm, z 130–133 |
| arm base plate | 100 × 120 mm, centred, z 133–186 |
| turret axis | (2, 1, 186) mm, reach ~525 mm |
| wheel radius / track / wheelbase | 0.036 / 0.2899 / 0.2393 m |
| `lidar_frame` | (117.4, 0, 96.5) mm |
| `camera_link` (realsense) | (199.1, 0, 68.5) mm |
| `imu_link` | (−9.9, −0.1, 99.0) mm |
| composed robot links | 61 (arm variant, jaws) |
| collision triangles | 0 chassis, ~5.4k total (gripper meshes only) |
| visual triangles | ~92k (chassis + arm) |
| disable_collisions in the SRDF | ~1022 (167 arm-internal + 855 chassis, tool=jaws) |

## 9. What failure looks like

| symptom | likely cause |
|---|---|
| arm renders no sliders in either web UI | the UI group table doesn't match the controller's joint names |
| controller stays `inactive`, arm never moves | `controllers.sim.yaml` names a joint the URDF doesn't have — run check 1b |
| MoveIt plans but execution does nothing | sim came up with `arm_control:=sliders`; the trajectory controllers aren't running |
| every plan fails, even `home`→`ready` | collision matrix under-disabled; adjacent links report permanent collision |
| planner routes through the chassis | matrix over-disabled; regenerate with more trials (5c) |
| base101 arm is a different size from mod101's | `arm.xacro` stopped passing the four build args; it falls back to macro defaults silently |
| `xacro: unterminated`/`not well-formed` in a comment | a `--` inside an XML comment; not legal, and it bites often here |
| build fails on a missing symlink | stale `--symlink-install` artifact; `rm -rf build/<pkg> install/<pkg>` |

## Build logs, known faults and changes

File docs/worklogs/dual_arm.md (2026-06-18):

# Dual mod101 arms worklog

> **Note (post-consolidation):** the arms now live in `base101_dual_arm`.
> `base101_description/urdf/base101_arms.xacro` → `base101_dual_arm/urdf/
> arms.xacro`; `base101_control/config/controllers.arms.yaml` →
> `base101_dual_arm/config/controllers.arms.yaml`.

Notes from mounting two mod101 arms on the cross tower's crossbeam brackets.
Current state is `base101_dual_arm/urdf/arms.xacro` +
`base101_dual_arm/config/controllers.arms.yaml` at HEAD. The tower itself has
its own worklog: [`tower.md`](tower.md).

## Design constraints

- mod101 must stay a **standalone repo** — no base101 knowledge inside it,
  and its single-arm bringup must keep working unchanged.
- Two instances of the same arm in one URDF means every link, joint,
  ros2_control system, gazebo reference, and sensor topic needs a unique
  name.

## mod101 refactor (done in the mod101 repo)

`mod101_description/urdf/mod101.xacro` was a flat 776-line robot file with
joints named `1…5` and a hardcoded `world` anchor. It was split into:

- **`mod101_macro.xacro`** — `xacro:macro mod101_arm(prefix, parent, xyz,
  rpy, tool, use_sim)`. Every link/joint name gets `${prefix}`; a fixed
  `${prefix}base_mount` joint attaches `${prefix}base_link` to `parent`
  (empty `parent` = no mount joint). The per-instance ros2_control block,
  gazebo link extensions (incl. the wrist camera, topic
  `${prefix}wrist_camera/image_raw`), and the selected tool are all emitted
  inside the macro.
- **`mod101.xacro`** — thin standalone wrapper: same `use_sim`/`tool` args
  as before, the `world` anchor, the (once-per-robot) gz_ros2_control
  plugin block, and one `prefix=""` macro call.
- The four tool packages' `tool.urdf.xacro` / `tool.ros2control` /
  `tool.gazebo` became macros too (`mod101_tool_<name>[...](prefix,
  use_sim)`), with `$(arg use_sim)` replaced by the macro param.

The conversion was script-driven (regex prefixing of `name=` / `parent
link=` / `child link=` / `mimic joint=` attributes) and verified by
canonical XML diff: the standalone URDF is **semantically identical** before
vs. after, except the anchor joint rename `world_to_base → base_mount`
(nothing referenced the old name).

## Mount geometry

Measured from the meshes, not guessed: the brackets are 80×120×30 mm slabs;
the mod101 base plate is 80×100 mm and sits centred on each bracket's top
face. In the bracket frames that's `(0, +0.06, 0.024)` (left) /
`(0, -0.06, 0.024)` (right). Mount yaw **0** = arms reach toward the robot's
front; the first guess of yaw π pointed them backwards (the arm's ready
stance reaches opposite to its CAD-zero direction — empirically corrected).

## Integration points (this workspace)

- `arms` + `arm_tool` xacro args in `base101.xacro`;
  `base101_arms.xacro` instantiates `left_arm_` / `right_arm_`.
  `arms:=true` requires `tower:=true` (the brackets are tower links).
- Arms get sim ros2_control only for `simulator == gazebo`
  (`arms_use_sim` property); mujoco scenes don't model them yet.
- `controllers.arms.yaml` (left/right arm + gripper position controllers)
  is added to the gz_ros2_control plugin's `<parameters>` list behind
  `$(arg arms)` in both variant `.gazebo` files; spawners + per-side wrist
  camera image bridges are conditional in `gazebo.launch.py`.
- `GZ_SIM_RESOURCE_PATH` must include the mod101 underlay's share dirs —
  the **tool** meshes use `package://mod101_tool_<name>/...` URIs (the arm
  meshes are `file://$(find ...)` and resolve at xacro time). Forgetting
  this = invisible grippers + "Failed to load geometry" for jaws parts.
- Build: mod101 underlay first, then this workspace with
  `--cmake-args -DPython3_EXECUTABLE=/usr/bin/python3` (a stray
  `~/.local/bin/python3.11` on PATH otherwise breaks `ament_package_xml`
  and rosidl's `import em`).

## Bugs & gotchas hit along the way

- **Lift sagged to its bottom stop** once the arms were added: carriage +
  arms ≈ 12 kg ≈ 118 N > the joint's 100 N effort limit. Raised to 400 N
  (see tower worklog).
- **Stale `robot_state_publisher` poisons ros2_control.** controller_manager
  takes the *first* `/robot_description` it hears and logs
  `ResourceManager has already loaded a urdf. Ignoring attempt to reload`
  for the real one. Symptom: spawners die with `command interface
  left_arm_1/position is not available` while the URDF is fine. Kill every
  node from previous sim runs before relaunching — and when scripting the
  cleanup, use patterns that can't match your own shell
  (`pgrep -f 'rosboard_nod[e]'`-style bracket trick), or the `pkill -f`
  kills the cleanup script itself.
- gz_ros2_control happily initialises **five** hardware systems from one
  URDF (base + 2× arm + 2× tool) under a single controller_manager — no
  special handling needed beyond unique system names (`${prefix}…`).

## Teleop

- `base101_teleop` package: stdlib-only HTTP server (`:8700`) + one
  embedded HTML page; sliders publish full group arrays to the controller
  topics, base pad publishes Twist to `/cmd_vel_key` at 10 Hz while held
  (twist_mux's 0.5 s timeout is the dead-man).
- rosboard **Joint sliders** card (`JointCommandViewer.js`): a real
  `/joint_states` subscriber viewer that publishes
  `std_msgs/Float64MultiArray` over the existing `MSG_PUB` websocket
  channel. Backend changes: type added to `publish_allowlist` +
  `_dict_to_ros` converter. The zero-on-silence publish watchdog only
  handles Twist types **by design** — zeroing a position-command topic
  would slam every joint to 0. `initSubscribe()` gained an optional
  `viewerName` override (persisted) so the System-nav entry can open
  `/joint_states` with the slider card instead of the default
  `JointStateViewer`.

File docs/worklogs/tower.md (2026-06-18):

# Cross tower worklog

> **Note (post-consolidation):** the tower now lives in its own package,
> `base101_dual_arm`. Paths below that say `base101_description/urdf/
> base101_tower.xacro` are now `base101_dual_arm/urdf/tower.xacro`
> (+ `tower.gazebo`, `tower.ros2control`), and the meshes are under
> `base101_dual_arm/meshes/tower/`. The geometry/debugging notes still apply.

Notes from merging `base101_cross_description` (a standalone Fusion CAD
export of the simple chassis + tower) into the base101 workspace, plus the
geometry-debugging passes that followed. Current state is whatever's in
`base101_dual_arm/urdf/tower.xacro` at HEAD.

## Origin

`base101_cross_description` was a fresh CAD export containing the **whole
robot**: a duplicate of the simple chassis plus the new tower assembly
(column, lift carriage, crossbeam, arm brackets, camera support, pan/tilt
head). Its `.ros2control` file was empty and its `.gazebo` file was
materials-only, so the only genuinely new content was 13 tower links/joints
and their meshes. The chassis duplicate was dropped; the tower was extracted
into `base101_description/urdf/base101_tower.xacro` with link/joint names and
origins kept verbatim from the export (meshes → `meshes/tower/`).

## Variant-aware attachment

The export shares its `core_top_plate_v1_1` frame with the **simple**
variant's export, so the tower's attachment joint (`Rigid 79`) transfers
verbatim for simple. The **pro** export's plate frame sits at the *opposite
corner* of the same physical plate (offset `(0.34, -0.24, 0)` — derived by
comparing the lidar-mount and bumper joint origins across exports), so
`base101_tower.xacro` picks the mount origin per variant:

- simple: `-0.17 0.12 0.003`
- pro: `0.17 -0.12 0.003`

Both put the column at the plate centre (verified numerically via FK).

## Integration points

- `tower` xacro arg in `base101.xacro` (default `false`), threaded through
  `gazebo.launch.py`, `display.launch.py`, `control_stack.launch.py`, and
  the hardware overlay.
- Tower joints (`lift`, `head_pan`, `head_tilt`) added to all three
  ros2_control files behind `<xacro:if value="$(arg tower)">`; the mujoco
  block needs matching joints in the scene XML before it's usable there.
- `tower_controller` (`position_controllers/JointGroupPositionController`,
  joints `[lift, head_pan, head_tilt]`) added to all controller YAMLs and
  spawned conditionally from the launches.
- Head camera sensor on `head_camera_1` in `base101_tower.gazebo` (same
  camera model as `base_camera`) + a `ros_gz_image` bridge in the launch.
- `self_collide` is **off** on the lift carriage chain — the mount/connector
  slide along (and overlap) the column, and resolving those contacts makes
  the prismatic joint fight the physics engine.

## Bugs found & fixed after the merge

### Lift limits and effort

The CAD export's limits (`0.03 … 0.52`, velocity 100 m/s) were wrong. Real
travel is ±0.26 m around mid-stroke; the axis points **down**, so `+0.26` is
the bottom. Velocity clamped to 0.5 m/s for sim stability. The effort limit
was raised 100 → 400 N after the dual-arm integration: the loaded carriage
(crossbeam 3.7 kg + brackets 2.6 kg + two arms & tools ≈ 4 kg ≈ 118 N of
gravity) exceeded 100 N, so in Gazebo the joint silently sagged to its
bottom stop and could not lift back ("commanded 0.1, reads 0.26" is the
symptom to remember).

### head_pan orbited instead of panning

The exporter anchored the `head_pan` joint at `head_pan_1`'s arbitrary link
frame — ~15 cm off the real pivot (design `(-0.0767, -0.1505, 1.26)` vs. the
hardware cluster at `y≈-0.054, z≈0.78-0.86`). Panning swung the whole head in
an arc; it only looked right at zero. The true shaft was measured from the
meshes: slicing `head_pan_camera_1.stl` (the pan motor) and `head_pan_1.stl`
(the bracket) shows the motor's top-face circle and the bracket's bottom hub
both centred at design `(-0.0219, -0.0549)`. The joint origin was moved
there, with `head_pan_1`'s visual/collision/inertial origins and the
`Rigid 87` child offset compensated so the zero pose is byte-identical
(verified by FK diff). Axis flipped to `+Z` so positive pan = CCW/left
(REP-103 yaw).

### Misnamed base-camera meshes

Both variant CAD exports shipped the *base* camera mesh under the name
`head_camera_1.stl` and never shipped `base_camera.stl` — which both
`base101_simple.xacro` and `base101_pro.xacro` reference. That was the
long-standing "Failed to load geometry for visual: …base_camera…" error in
Gazebo. Identity was confirmed by matching each STL's bounding-box centre
against the base_camera link's CoM, then the files were renamed to
`base_camera.stl` in `meshes/simple/` and `meshes/pro/`. (The tower's actual
head camera mesh lives at `meshes/tower/head_camera_1.stl` — no conflict.)

## Debugging techniques worth keeping

- Fusion-style exports place every link frame axis-aligned with the design
  frame; a link's design-frame position is simply `-(visual origin)`. That
  identity makes cross-export frame reconciliation and FK spot-checks cheap.
- Binary STL slicing (1 mm z-bands, per-band XY centroid + radius spread)
  reliably locates motor shafts, hubs, and bolt-pattern centres when the
  export's joint anchors can't be trusted.
- When a controller "fails to activate" with `command interface X/position
  is not available`, check whether the controller_manager logged
  `ResourceManager has already loaded a urdf` — a stale
  `robot_state_publisher` from a previous run published an old
  `/robot_description` first. Kill *everything* between sim runs.

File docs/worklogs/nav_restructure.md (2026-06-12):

# base101 nav restructure — preparation for robocore autonomy

Per `bpe/nav_setup.md` (Cristi, 2026-06-12), plus two rulings given
during implementation: section 12 wins (behavior_server removed
entirely), and SLAM/Nav2 must be independently launchable — "feel free
to even split it into a different package", so it is one.

## What changed

**New package `base101_slam`** — the localization half:
- `launch/slam.launch.py`: robot_localization EKF (config picked by
  `use_sim_time`: ekf.sim.yaml vs ekf.yaml) + slam_toolbox
  (async, mapping mode) + its own lifecycle manager
  (`lifecycle_manager_slam`, only slam_toolbox — EKF is not a lifecycle
  node). Args: `use_sim_time`, `autostart`, `slam_config` override.
- `config/slam_toolbox.yaml`: unified config, the tested
  online_mapping.yaml values (Ceres solver, 8 m laser range, 0.15 m /
  0.2 rad travel thresholds, tighter loop-closure gates). Mode switching
  is a SERVICE CALL (`/slam_toolbox/serialize_map`,
  `/slam_toolbox/deserialize_map`), never a process restart — no
  separate localization config anymore.
- `config/ekf.sim.yaml`, `config/ekf.yaml`, `config/lifelong_mapping.yaml`
  (marked "not currently used") and `maps/` moved here from base101_nav.

**`base101_nav` is now pure Nav2:**
- `launch/nav.launch.py`: planner_server (Smac2D), controller_server
  (MPPI, cmd_vel→cmd_vel_raw), bt_navigator, velocity_smoother
  (cmd_vel_raw→cmd_vel_nav), own lifecycle manager
  (`lifecycle_manager_nav`). 3 s-delayed lifecycle managers,
  bond_timeout 30 s, autostart arg.
- `behavior_trees/nav_to_pose.xml`: minimal — plan/follow/fail. No
  RecoveryNode, no retries, no spin (tower + dual arms), no wait. Nav2
  returns ABORTED; the bridge yields NavStatus(phase="stuck"); Python
  decides. The bridge clears both costmaps before each goal via the
  costmap clear services (no behavior_server to do it).
- `config/costmap.yaml`: unified for all modes. Global: rolling_window
  false, 3.0/2.0 Hz update/publish (the SLAM map GROWS in mapping mode),
  track_unknown_space true (frontier finding is a Python concern now),
  static_layer subscribe_to_updates + map_topic /map.
- package.xml/CMakeLists slimmed: ament_cmake only, exec_depends on the
  five nav2 packages actually launched (+ smac/mppi plugins). Dropped:
  nav2_amcl, nav2_behaviors, nav2_map_server (moved to base101_slam for
  map_saver_cli), slam_toolbox, robot_localization, explore_lite, rclpy.

**Independence (Cristi's ruling):** neither package references the
other. Separate lifecycle managers mean no bond coupling: Nav2 starts,
runs and dies without slam_toolbox and vice versa. The only remaining
coupling is the `/map` topic + `map->odom` TF — consumed from whatever
publishes them.

**Deleted** (sections 2, 6, 7, 9, 12): mode_manager.py + its two
launches, mapping/navigation/mapfree/slam_nav launches (8 files),
costmap_mapfree.yaml, online_mapping.yaml, slam_toolbox_localization.yaml,
amcl.yaml, explore.yaml, behavior.yaml. Also the stray
`config/{build,install,log}` dirs from an accidental in-config colcon
run. The mode_manager's jobs (mode switching, map discovery/saving,
status) move to the robocore bridge in Phase 5.

**Sim IMU (Cristi: add it):** `base_imu` gz sensor on base_link at
100 Hz → `/sensors/imu`, bridged (gz.msgs.IMU → sensor_msgs/Imu);
`gz-sim-imu-system` added to empty.sdf (sticky_floor already had it).
This makes ekf.sim.yaml's imu0 input real instead of a dead topic, and
gives robocore's imu API live sim coverage. The robocore profiles
(engine/profiles/base101*.yaml) gained `imu: {topic: /sensors/imu}`.

## Two launch bugs found and fixed during bring-up

1. **slam_toolbox bond loop under sim time.** With a nav2 lifecycle
   manager driving it, the manager reported "Server slam_toolbox
   connected with bond" then "no heartbeat for 30000 ms" ~200 ms later,
   looping deactivate/reactivate forever. The bond heartbeat misfires on
   the sim clock. Removing the manager doesn't work either:
   slam_toolbox is a LifecycleNode that does NOT self-activate — it sits
   in `unconfigured` until something drives configure->activate. Fix:
   keep the manager (it must autostart slam) but set `bond_timeout: 0.0`,
   which makes nav2 skip bond creation entirely. Manager still
   activates; no heartbeat watchdog to misfire. Crash supervision is the
   bridge's job anyway.
2. **`nav_through_poses.xml` referenced absent action servers.** It was
   the canonical nav2 recovery tree (Spin/Wait/BackUp). With no
   behavior_server, bt_navigator refused to ACTIVATE ("Action server
   spin not available") and aborted the whole nav bringup — not just
   nav_through_poses. Replaced with a minimal plan/follow/fail tree
   (RemovePassedGoals is BT-internal, kept for waypoint progress).

Process lesson worth remembering: colcon's `install(DIRECTORY)` did not
recopy edited launch/config files on an incremental build ("1 package
finished" but the installed file was unchanged), so several fixes looked
ineffective while the stack kept running the old launch. `rm -rf
build/<pkg> install/<pkg>` before rebuild forces it.

## Verification — all green against the live stack (2026-06-12)

- [x] gazebo.launch.py starts cleanly (with sim IMU + depth additions)
- [x] slam.launch.py + nav.launch.py start independently; all 5 lifecycle
      nodes reach `active`
- [x] slam_toolbox publishes /map and a live map->odom TF
- [x] NavigateToPose SUCCEEDED while mapping (drove -0.82 -> 0.38 m to a
      0.8 m goal)
- [x] Map save: serialize_map (result=0, .data+.posegraph) + map_saver_cli
      (.pgm+.yaml)
- [x] Map load: deserialize_map match_type=LOCALIZE_AT_POSE switched to
      localization; map->odom keeps publishing
- [x] NavigateToPose SUCCEEDED after the localization switch (drove to a
      (0,0.5) goal)
- [x] No behavior_server / AMCL / explore_lite / mode_manager processes
- [x] Costmap clear services callable (clean Empty response on both)
- [x] twist_mux priorities: navigation /cmd_vel_nav = 10 < agent = 50
- [x] /sensors/imu publishes (BEST_EFFORT — use that QoS to echo); EKF
      outputs /odometry/filtered fusing odom + imu

Not run (deferred): blocked-path -> ABORTED timing. The minimal BT has no
RecoveryNode so a planner/controller failure returns ABORTED by
construction; staging a live obstacle to time it belongs with the Phase 5
navigate() generator work, where the bridge maps ABORTED ->
NavStatus(phase="stuck").

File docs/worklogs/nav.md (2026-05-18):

# Navigation worklog

Notes from porting Nav2 + slam_toolbox + frontier exploration into the
base101 workspace, plus the debugging passes that followed. Written
chronologically; the "current state" is whatever's in `src/base101_nav/`
and `base101.repos` at HEAD.

## Origin

The stack was ported from `LLMy/ros/src/llmy_nav` (the LLMy repo had two
candidates, `llmy_slam` and `llmy_nav`; `llmy_nav` is a strict superset
that already includes the slam_toolbox configs, so `llmy_slam` was
dropped). Rename happened in one pass:

- `cp -r llmy_nav → src/base101_nav`
- Python module dir, resource marker, `package.xml` `<name>`, and
  `CMakeLists.txt` `project()` all renamed.
- Bulk `sed` of `llmy_nav → base101_nav` and `~/.llmy/maps → ~/.base101/maps`
  across launch files, configs, README, and `mode_manager.py`.
- Dropped `llmy_description` / `llmy_camera` deps from `package.xml`.

## Adaptations vs LLMy

| Area | LLMy (origin) | base101 (after) |
|---|---|---|
| Drive type | omnidirectional_controller | diff_drive_controller |
| Wheel separation | 0.176 m | 0.38 m |
| Wheel radius | 0.025 m | 0.05035 m (DDSM115) |
| Footprint | 0.30 × 0.20 m | 0.50 × 0.48 m (`[[0.25, 0.24], ...]`) |
| Velocity caps (controller) | 0.5 / 1.0 m/s, rad/s | 1.2 / 2.0 (hw allows 1.5 / 2.5) |
| Odom topic | `/omnidirectional_controller/odom` | `/diff_drive_controller/odom` (was already correct in LLMy ekf configs) |
| EKF `base_link_frame` | `base_footprint` | `base_link` |
| EKF `publish_tf` | `true` | `false` (diff_drive_controller already owns `odom→base_link`; two publishers would conflict) |
| SLAM `base_frame` | `base_footprint` | `base_link` |
| BT `odom_topic` | `/odom` | `/diff_drive_controller/odom` |

The Nav→controller wiring (`velocity_smoother → /cmd_vel_nav →
twist_mux → /diff_drive_controller/cmd_vel`) needed no changes —
`/cmd_vel_nav` was already what base101's twist_mux expected.

## Runtime deps

apt-installable (`ros-jazzy-*`):
- `nav2_{map_server,amcl,planner,smac_planner,controller,bt_navigator,
  behaviors,velocity_smoother,lifecycle_manager,msgs}`
- `slam_toolbox`, `robot_localization`
- `nav2_regulated_pure_pursuit_controller` (replaced `nav2_mppi_controller` —
  see "Controller choice" below)

Not in apt — vendored via `base101.repos` at workspace root:
- `explore_lite` + `explore_lite_msgs` (`map_merge` is `COLCON_IGNORE`d).
- Source repo: `github.com/robo-friends/m-explore-ros2`, pinned to commit
  `86742bff6edd53fcce16f99dbc8c06ed5d7eed22` on `main`.

Bring-up for collaborators:

```bash
vcs import src < base101.repos
sudo apt install ros-jazzy-nav2-{map-server,amcl,planner,smac-planner,controller,bt-navigator,behaviors,velocity-smoother,lifecycle-manager,msgs,regulated-pure-pursuit-controller} ros-jazzy-slam-toolbox ros-jazzy-robot-localization
colcon build
```

## Launch files (what each one does)

Five launches, each in `.py` and `.yaml` flavors (identical behavior,
pick your preferred format).

- **`mapping.launch.py`** — pure SLAM. Just `slam_toolbox` (async) + its
  lifecycle manager. Drive around, save the map via service.
- **`navigation.launch.py map:=<map.yaml>`** — pure Nav2 with a
  pre-built map. `map_server` + `amcl` + planner + RPP controller +
  bt_navigator + behaviors + velocity_smoother + lifecycle manager.
- **`mapfree.launch.py`** — Nav2 without a map. Identity `map→odom`,
  rolling-window costmaps. Assisted teleop with obstacle avoidance.
- **`slam_nav.launch.py [explore:=true]`** — SLAM + Nav2 simultaneously.
  Now uses SLAM's `/map` as the global costmap's static layer (was
  rolling window in `costmap_mapfree.yaml`, see "Fix #1" below).
- **`mode_manager.launch.py`** — runs `mode_manager.py` which exposes
  `/nav/{change_mode,save_map,stop}` services and subprocess-spawns the
  above launches.
- **`rviz.launch.py`** — opens RViz with `config/nav.rviz` (copy of
  `nav2_bringup/rviz/nav2_default_view.rviz`, Map / costmaps / paths /
  Nav2 goal panel preloaded).

Always pass `use_sim_time:=true` when running against Gazebo, on every
launch including RViz — otherwise TF lookups silently fail (see "Bug
trail" below).

## Sensor frame fix (gpu_lidar)

Side-effect change in `base101_description/urdf/base101_*.gazebo`:
moved the `<sensor type="gpu_lidar">` block from
`<gazebo reference="lidar_1">` to `<gazebo reference="lidar_frame">`.
Before: rays were cast from the mesh origin while `/scan` was stamped
with `lidar_frame`, so the data was offset ~3 cm from where TF said it
came from. After: rays come from the laser plane, stamp matches. The
material/friction props stayed on `lidar_1` (where the mesh and
collision geometry live).

## Controller choice

**Final answer: MPPI, with TurtleBot4's canonical params + raised
velocity caps for base101 hardware.** `controller.yaml` is a direct
adoption of `turtlebot4_navigation/config/nav2.yaml`'s MPPI block,
which itself follows `nav2_bringup` defaults.

The path here had a detour. Original config (from LLMy) was MPPI.
Mid-debugging, swapped to **Regulated Pure Pursuit (RPP)** on the
reasoning that "MPPI is overkill for indoor diff drive" — ~1/20th the
compute, ~6 knobs instead of ~30. Worked, but at that point the real
problems were the costmap inflation pattern and the BT recovery loops,
not the controller. RPP was solving a problem we didn't actually
have, and at the cost of weaker handling of:
- **Dynamic obstacles** — MPPI samples 2000 trajectories around them;
  RPP just follows the global path and asks the planner to replan.
- **Tight maneuvers** — MPPI deviates from path to fit; RPP slows or
  aborts.
- **Smooth motion** — MPPI's critic system balances competing
  objectives; RPP is rigid path-following.

After the costmap and BT were fixed against the canonical pattern,
re-evaluated: MPPI is what Nav2 ships and what TB4 uses. CPU isn't a
constraint on dev hardware (~20% of one core), and even an SBC
handles it. **Swapped back.**

Only deviations from TB4 in our MPPI block:
- `vx_max: 0.5 → 1.0` (base101 is bigger and faster; hw allows 1.5).
- `vy_max: 0.5 → 0.0` (cosmetic — DiffDrive motion model zeros it
  anyway, but clearer this way).

Tunables most likely to touch (in priority order):
- `vx_max`, `wz_max` — velocity envelope.
- `PathAlignCritic.cost_weight` (14.0) — how rigidly to follow the
  global path. Lower → more willing to cut corners around obstacles.
- `PreferForwardCritic.cost_weight` (5.0) — penalty for reverse motion.
- `CostCritic.cost_weight` (3.81) — penalty for being near obstacles.
- `batch_size` (2000) — drop to 1000 if CPU-bound on an SBC.

Lesson echoed from the costmap section: when in doubt, **stay on
canonical**. Swapping for "simpler" is rarely the right call unless
you can name a specific behavior the canonical thing is doing wrong.

## Bug trail

### TF extrapolation: `Requested time 1779091262 but latest data is at 813`

Classic sim/wall-clock mismatch. `slam_toolbox` was on sim time (TF
stamped at sim-second ~813), planner_server + behavior_server +
explore_node were on wall time (looking for unix epoch ~1.78e9). The
TF buffer in wall-time nodes considered the sim-stamped frames ~1.7e9
seconds in the past and gave up. Hence every plan aborted and explore
reported "all frontiers traversed" — it never managed a single pose
lookup.

**Fix:** `use_sim_time:=true` on every launch when in Gazebo. Launch
files already propagate it; default stays `false` for portability to
hardware.

### TF extrapolation: `Requested time 9.092 but earliest data is at 13.1`

Different shape, both on sim time. explore_node's `TimerAction`
started it at sim-second ~9, before slam_toolbox had published the
first `map→odom` (around sim-second 13). The initial goal's stamp
predated the TF buffer.

**Fix:** bumped explore start delay 20 → 30 s in `slam_nav.launch.py`.
Cosmetic — explore_lite retries and recovers on its own — but keeps
startup logs clean.

### EKF removed from slam_nav

`ekf_filter_node` was in the original launch. With no IMU on base101,
EKF on wheel odom alone is a glorified passthrough that adds latency.
Removed the node and the 10-second `TimerAction` that was waiting for
it to publish `odom→base_link`. Configs (`ekf.yaml`, `ekf.sim.yaml`)
left in place with `publish_tf: false`; re-enable once an IMU is
wired in.

### `Ignoring the received message ... older than 0.5s`

`diff_drive_controller` was rejecting cmd_vel messages as stale.
Stamps were sim-time (good), but ~0.8 s behind current sim time. Root
cause was Gazebo RTF dropping under Nav2 load — sim time advances
slower than wall time, and the cmd_vel pipeline (planner → smoother →
twist_mux → diff_drive_controller) accumulates real-time latency that
shows up as sim-time staleness.

**Fix:** raised `cmd_vel_timeout: 0.5 → 2.0` in
`base101_control/config/controllers.{pro,simple}.sim.yaml`. Left HW
config strict at 0.5 s. If you need to debug RTF:
`gz topic -e -t /world/<world>/stats`.

### "Courageous leaps, then minutes of recomputing"

From `mapping_navigation.log`: 72 planner aborts, 30+ "Goal Coordinates
outside bounds", 20+ "RegulatedPurePursuitController detected collision
ahead", 23 spin/backup recoveries firing in cycles of ~20-30 s each.
Multiple root causes stacked:

1. **`slam_nav` used a rolling 10×10 m global costmap** (from
   `costmap_mapfree.yaml`) while explore picked frontiers up to 7+ m
   away from the SLAM `/map`. Goals outside the 5 m radius window =
   "outside bounds". → Switched `costmap_mapfree.yaml`'s global_costmap
   to a static layer subscribed to `/map`, frame=`map`,
   `rolling_window: false`. Local costmap stays rolling.

2. **Inflation 0.35 m on a 0.50×0.48 m footprint = thick personal
   bubble.** Spin and backup recoveries both failed with "Collision
   Ahead" because the inflated halo around the robot intersected
   itself when projected. → 0.35 → 0.25 in all three configs
   (`costmap.yaml`, `costmap_mapfree.yaml`, RPP's ObstaclesCritic
   mirror in `controller.yaml`).

3. **RPP forward collision check too aggressive.** At 1.2 m/s with
   `max_allowed_time_to_collision_up_to_carrot: 1.0`, the projected
   carrot was 1.2 m ahead — well into the inflation halo of any
   nearby obstacle. → 1.0 → 0.4 s. Also dropped `cost_scaling_dist`
   0.6 → 0.4.

4. **Explore picked unreachable frontiers.** `min_frontier_size: 0.3`
   caught noise pixels at map edges. → 0.3 → 0.6. Bumped
   `potential_scale: 3.0 → 5.0` (stronger distance penalty, prefer
   nearby).

### Follow-up: "no valid path found" everywhere after the StaticLayer swap

Round-2 symptom: the SLAM-static-layer fix above introduced a worse
failure — robot sat at spawn forever, planner replanned at 1 Hz with
the controller logging "Passing new path to controller" 12+ times
without any motion, then progress_checker killed the goal.

Root cause: `track_unknown_space: true` on the global_costmap meant
unknown cells from SLAM's `/map` were treated as not-passable. When
SLAM has just started, ~everything is unknown — robot sits on a tiny
island of known-free cells, frontiers (by definition) border unknown,
and the planner can't cross the unknown gap to reach them.

Fix: `track_unknown_space: false` on the global_costmap +
`trinary_costmap: true` on the static_layer (don't preserve the
unknown=gray middle value, collapse to free/lethal). Planner now
crosses unknown freely; obstacle_layer catches anything live lidar
sees.

Also bumped the BT's `RateController hz="1.0" → "0.5"` — replanning at
1 Hz spammed "Passing new path" and made the log unreadable. 0.5 Hz
is still plenty for indoor speeds.

### Inflation rewrite (the actually-important fix)

After all the above tuning the robot was still getting trapped easily.
Compared our config to two reference Nav2 setups (upstream
`nav2_bringup/params/nav2_params.yaml` on jazzy, TurtleBot4's
`turtlebot4_navigation/config/nav2.yaml`). Discovered we'd been using
a fundamentally wrong inflation pattern, copy-pasted from somewhere
without understanding what it meant:

| | Nav2 default | TurtleBot4 | Ours (was) |
|---|:---:|:---:|:---:|
| `inflation_radius` | 0.70 m | 0.45 m | 0.25 m |
| `cost_scaling_factor` | 3.0 | 4.0 | 10.0 |

The cost formula is `(cost_max - 1) * exp(-cost_scaling_factor *
(distance - inscribed_radius))`. With our small radius + steep
scaling, the cost map looked like a binary cliff: ~free outside 25 cm,
near-lethal inside. The planner had to thread perfect needles past
obstacles; RPP's forward collision check tripped on its own
inflation halo at any speed; recoveries failed because spin/backup
projection always intersected the halo.

The canonical pattern is the inverse: **large radius + gentle
scaling**, so cost rises smoothly from obstacles. Planner naturally
prefers centered corridors but can still squeeze through tight gaps
when needed, and RPP/recoveries see a soft cost gradient instead of a
wall.

Changes (applied to both `costmap.yaml` and `costmap_mapfree.yaml`):

- `inflation_radius`: 0.25 → **0.55** (a bit larger than TB4 since
  base101 is slightly bigger).
- `cost_scaling_factor`: 10.0 → **3.0** (Nav2 default).
- `controller.yaml`'s `inflation_cost_scaling_factor`: 10.0 → **3.0**
  (MUST match the inflation layer or RPP miscalculates proximity).
- `controller.yaml`'s `cost_scaling_dist`: 0.4 → **0.55** (match
  inflation radius).
- `controller.yaml`'s `max_allowed_time_to_collision_up_to_carrot`:
  0.4 → **1.0** (with gentle gradient, the carrot doesn't false-trip).

Also brought update frequencies in line with Nav2 defaults (we were
3-5× over):

- global_costmap `update_frequency`: 5.0 → **1.0 Hz**
- global_costmap `publish_frequency`: 2.0 → **1.0 Hz**
- local_costmap `update_frequency`: 10.0 → **5.0 Hz**
- local_costmap `publish_frequency`: 5.0 → **2.0 Hz**

This single change set is more impactful than every previous tuning
round combined. Lesson: when copying configs, copy from the *canonical*
reference (`nav2_bringup`), not from a derivative project — derivatives
often have undocumented bot-specific tweaks that don't generalize.

### BT and behavior plugins audit

Same "copy from canonical" pass on the behavior trees. Both
`nav_to_pose.xml` and `nav_through_poses.xml` were derivatives missing
the `<WouldAPlannerRecoveryHelp>` / `<WouldAControllerRecoveryHelp>`
guards introduced in jazzy. Those guards inspect the planner/controller
error code before triggering recovery — e.g. "invalid goal" errors no
longer waste ~10 s on spin/backup attempts that can't help.

Replaced both BTs with the canonical Nav2 jazzy versions
(`navigate_{to_pose,through_poses}_w_replanning_and_recovery.xml`) and
kept exactly one local tweak: `Wait wait_duration: 5.0 -> 2.0`. Reverted
several of our earlier "compensation" tweaks now that the costmap is
sane:

- Top-level `RecoveryNode number_of_retries`: 2 → **6** (canonical)
- `RateController hz`: 0.5 → **1.0** (canonical; nav_through_poses
  uses 0.333)
- `BackUp` 0.20 m → **0.30 m** (canonical)
- Added `error_code_id` on `<Spin>` and `<BackUp>` so the BT propagates
  *why* a recovery failed, not just that it did.
- `nav_through_poses` now includes `<RemovePassedGoals radius="0.7">`
  inside a `ReactiveSequence` (was missing, meaning passed waypoints
  weren't being pruned).

For the `behavior_server` config: registered all five Nav2-default
plugins (was `spin, backup, wait`; added `drive_on_heading,
assisted_teleop`). They don't run unless referenced from a BT, but
this avoids "plugin not registered" surprises if we want to add a
`drive_on_heading` nudge to the recovery round-robin later.

Also bumped `max_rotational_vel: 1.0 → 1.5` on behavior_server so
`<Spin>` actually rotates at the rate base101 hardware allows.

5. **BT retried for ~90 seconds before failing.** `RecoveryNode
   number_of_retries="6"` × ~15 s/cycle = ~90 s. → 6 → 2 (~30 s).
   Also shortened the `Wait wait_duration` 5.0 → 2.0 s and made
   backup faster: `backup_dist: 0.30 m @ 0.05 m/s` (6 s) →
   `0.20 m @ 0.15 m/s` (~1.3 s). Same edits applied to both
   `nav_to_pose.xml` and `nav_through_poses.xml`.

## Velocity tuning history

Three passes:

1. Initial: vx_max 0.8, wz_max 1.5, smoother accel 0.5 m/s² → too slow
   to react, robot felt mushy.
2. Sped up: vx_max 1.2, wz_max 2.0, accel 1.5 m/s², smoother 30 Hz →
   better but courageous leaps interspersed with stuck cycles.
3. Stuck cycles fixed via costmap/BT changes above; velocities kept
   at pass-2 values.

`velocity_smoother.yaml` and `controller.yaml` must agree on caps.
Hardware caps in `controllers.{pro,simple}.sim.yaml` are 1.5 m/s and
2.5 rad/s; controller is configured 0.3 below hw to leave headroom
for the smoother to actually reach commanded velocities without
clipping at the diff_drive_controller layer.

## Plugin upgrades (round 3)

After the controller revert to MPPI, did a sweep of other Nav2 plugin
slots to align with canonical patterns / pick up obvious wins:

### Path smoother — added then reverted

First attempt: added a separate `smoother_server` running
`nav2_smoother::SimpleSmoother`, with `<SmoothPath unsmoothed_path="{path}"
smoothed_path="{path}" smoother_id="simple_smoother"/>` placed inside
the `ComputePathToPose` Sequence in both BTs.

**This broke FollowPath.** Symptom: every 1 s the controller logged
"Aborting handle" then "Passing new path to controller", cycling
forever. The robot never followed any single path long enough to make
progress, and eventually progress_checker killed the goal.

Root cause: BT blackboard race. Both `ComputePathToPose` and
`SmoothPath` wrote to the same `{path}` variable, but at different
points within the same cycle:

1. ComputePathToPose returns SUCCESS, writes to `{path}` → FollowPath
   sees update, starts following.
2. SmoothPath runs, eventually writes to `{path}` again → FollowPath
   sees a *second* update in the same cycle, treats it as a new goal,
   aborts the previous handle.

In a PipelineSequence (which ticks all children every round), this
mid-cycle mutation guarantees FollowPath aborts every cycle.

The fix-in-place would be writing to a separate `{unsmoothed_path}`
variable for ComputePathToPose then atomically swapping into `{path}`
via SmoothPath. But noticed a more important fact: **SmacPlanner2D
already has a built-in smoother** configured in `planner.yaml`
(lines 20-25 — `smoother: {max_iterations: 1000, w_smooth: 0.3, ...}`).
We were going to double-smooth anyway.

**Reverted:** removed SmoothPath from both BTs, removed smoother_server
node from both launches (+ lifecycle_manager node_names), deleted
`config/smoother.yaml`, dropped `nav2_smoother` from package.xml.
SmacPlanner2D handles smoothing internally, no race, no extra
lifecycle node.

Lesson: before adding a Nav2 plugin, check what the things you already
have ship with. Many planners do smoothing internally; many smoothers
need careful BT wiring to avoid blackboard races.

### Explore_lite — reverted to upstream defaults

Same review pass on `config/explore.yaml`. Found 5 deviations from
upstream's `params_costmap.yaml`, all of them band-aids for the
costmap problems that are now actually fixed:

- `planner_frequency`: 0.33 → **0.15** (gives robot time to drive to
  a frontier before reconsidering).
- `progress_timeout`: 20.0 → **30.0** s.
- `potential_scale`: 5.0 → **3.0** (the "prefer nearby" hack — was
  compensating for goals landing outside costmap bounds, which is no
  longer a thing).
- `transform_tolerance`: 1.0 → **0.3** (was raised when we had TF
  extrapolation chaos; fine now that sim_time is right).
- `min_frontier_size`: 0.6 → **0.75** (upstream's value; more
  conservative — skips small noise frontiers).

Also switched `costmap_topic` from SLAM's raw `/map` to the
inflation-aware `/global_costmap/costmap`. Two benefits:
1. Frontiers are picked in actually-passable space (respecting
   inflation around walls), so explore stops sending "looks-free-but-
   inflated-into-wall" goals that the planner can't reach.
2. Consistent with the upstream `params_costmap.yaml` variant, which
   is the recommended choice when used alongside Nav2.

Kept `return_to_init: false` (our preference — don't want the long
return trip during dev testing).

### Follow-up: "No frontiers found, stopping"

After switching `costmap_topic` to `/global_costmap/costmap`, explore
immediately said "No frontiers found, stopping" and quit. Self-inflicted
config conflict from two rounds ago:

1. Earlier (track_unknown_space round): set
   `global_costmap.track_unknown_space: false` so the planner could
   cross unknown cells while SLAM was still mapping.
2. Now (explore round): switched explore from `/map` to
   `/global_costmap/costmap` so frontier picks respect inflation.

Problem: `track_unknown_space: false` collapses unknown cells in the
costmap output to free. The costmap **no longer has unknown cells**,
so explore_lite finds zero frontiers (which are by definition
free/unknown boundaries).

The semantic confusion was mine: `track_unknown_space` controls
whether the costmap *distinguishes* unknown from free in its output
— it's *not* "should the planner respect unknown" (that's the
planner's `allow_unknown` setting, a separate knob entirely).

Right answer (Nav2's canonical SLAM+explore pattern):

- `global_costmap.track_unknown_space: true` → costmap output has
  unknown cells → explore_lite finds frontiers.
- `planner.allow_unknown: true` → planner is allowed to cross unknown
  cells when generating paths to those frontiers.

Both consumers get what they need from one costmap. Should have done
this in the first place; the original `track_unknown_space: false`
fix was working around `allow_unknown: false` on the planner, when
the cleaner fix was the inverse — flip the planner's switch and let
the costmap do its job.

Meta-lesson: when one component is doing the wrong thing, fix it at
the right layer. I changed costmap semantics to compensate for a
planner default; that fix worked locally but broke a consumer
downstream (explore). Cost: one full round of "explore is broken"
debugging that wasn't actually about explore.

## Final velocity / kinematics pass

After the stack was working end-to-end (paths correct, following
correct, no recovery firing) rotation still felt slow and overshooty.
Audit revealed three stacked issues:

### Velocity envelope was fictional

The MPPI block had `vx_max: 1.0` (carried over from earlier tuning
rounds). But the **simple** variant (DDSM210, 72.6 mm wheels) caps
at **210 RPM → 0.81 m/s real maximum**. We were commanding velocities
the hardware can't physically reach; the sim would happily oblige
(unconstrained motor models), but anything tuned at sim speeds
wouldn't transfer to hardware. Aligned MPPI + velocity_smoother caps
to the real envelope: `vx_max: 0.8`, `vx_min: -0.3`.

For the PRO variant (DDSM115, 100.7 mm wheel, higher RPM), the cap
would be ~1.5 m/s — leave a comment in the config to flip if/when we
test against the pro variant in sim.

### Rotation was undertuned at every layer

| Layer | Was | Now |
|---|---|---|
| MPPI `wz_max` | 1.9 rad/s | **2.5** (matches `controllers.simple.sim.yaml` hw cap) |
| MPPI `az_max` | 3.5 | 3.5 (unchanged — already at hw cap) |
| velocity_smoother `max_velocity[wz]` | 2.0 | **2.5** (was below MPPI's, capping output) |
| velocity_smoother `max_accel[wz]` | 2.5 | **3.5** (was throttling rotation onset) |
| GoalAngleCritic `cost_weight` | 3.0 | **6.0** (penalize off-heading harder → less orbiting / overshoot) |

Note the velocity_smoother had a lower wz cap than MPPI — meaning even
when MPPI commanded 1.9, the smoother clamped to 2.0 (so OK there),
but the accel limit of 2.5 rad/s² meant reaching that target took
~0.8s. Now ramps to full speed in ~0.5s.

### RTF tweaks for dev box

Three changes after Gazebo RTF dropped under the full Nav2 + RViz
load:

1. `worlds/{sticky_floor,empty}.sdf` `<max_step_size>`:
   0.001 → **0.003** (3x coarser physics — fine for indoor wheeled).
2. MPPI `batch_size`: 2000 → **1000** (half the per-tick controller
   compute; canonical Nav2/TB4 default is 2000, but unnecessary at
   our speeds).
3. Local costmap `update_frequency`: 5 → **3 Hz** (reactivity drop
   marginal for static-ish indoor).

If RTF is still bad after this, the heaviest single thing is RViz —
running it on another machine, or closing it during long exploration
runs, gives the biggest gain.

### explore_lite commitment: planner_frequency 0.15 → 0.05

With the upstream `planner_frequency: 0.15` (re-evaluate frontier
choice every ~7 s), the explorer kept swapping targets mid-trip as
the SLAM map grew and new frontiers appeared. Visually: robot drives
2 s toward A, switches to B, drives 4 s toward B, switches to C...
Made fast progress feel hesitant.

Dropped to **0.02 Hz** (every 50 s) — effectively "finish current goal
before picking the next." Most reachable goals complete inside that
window. The explorer only intervenes if `progress_timeout: 30 s` fires
first (genuinely stuck goal) or the trip exceeds 50 s.

### Re-reverted: costmap_topic back to /global_costmap/costmap

End-of-exploration symptom: explorer picked a frontier that *looked*
passable on SLAM's raw `/map` but was actually too tight for
footprint + 0.55 m inflation halo. Planner couldn't find a valid path,
robot retried the same frontier forever (the blacklist-on-progress-
timeout mechanism in explore_lite isn't reliable enough — the same
"tight spot" produced multiple adjacent frontier clusters and explore
kept picking new ones from the same unreachable zone).

Switched back to `/global_costmap/costmap` for the inflation-aware
frontier picks. Three changes to make the startup race we hit before
non-fatal:

1. `global_costmap.update_frequency`: 1.0 → **3.0 Hz** (canonical
   Nav2 default is for static maps; with a *growing* SLAM map we need
   the costmap to absorb new free cells fast enough that explore's
   first scan finds clear cells near the robot).
2. Explore launch delay in `slam_nav.launch.py`: 30 → **45 s** (gives
   SLAM and the costmap time to populate before explore runs `makePlan()`).
3. `planner_frequency`: 0.02 → **0.05 Hz** (every 20 s). The previous
   0.02 made explore_lite's "stop on first failed scan" behavior
   fragile — one transient hiccup at startup permanently ended
   exploration. 0.05 still commits the robot to each goal for most
   of its trip but allows reasonable recovery if a scan fails.

This is the third costmap_topic flip-flop. Locking in the rationale:
- `/map` (SLAM raw): explore sees free space SLAM has scanned, but
  doesn't see inflation → picks unreachable tight-corner frontiers.
- `/global_costmap/costmap`: inflation-aware, frontiers are
  reachable, but startup is fragile because the costmap has to fill
  before explore's first attempt.

The right answer is the second + careful startup hygiene, not the
first. Took two rounds to confirm.

### (Previously) Reverted costmap_topic: /global_costmap/costmap → /map

The earlier switch to `/global_costmap/costmap` (so frontiers respect
inflation) hit a new failure: at startup, the Nav2 costmap's FREE
cells take a while to populate (`update_frequency: 1 Hz`, plus initial
StaticLayer/ObstacleLayer fill time), and during that window
explore_lite sees no clear cell near the robot. Crucially, when
`makePlan()` fails, explore_lite calls `stop()` *permanently* — it
never retries. With `planner_frequency: 0.02 Hz` (50 s between
attempts), the first call is critical; if it fails, the session is
over.

Switched the source back to SLAM's raw `/map` topic. slam_toolbox
publishes free space around the robot from the very first scan, so
explore can find clear cells immediately. Tradeoff (knowingly
re-accepted): explore picks frontiers without seeing Nav2's
inflation, occasionally choosing goals near walls that the planner
then has to route around or fail.

If unreachable-frontier picks become a problem, the next move is to
keep `costmap_topic: map` but raise `min_frontier_size` (currently
0.75) so we only chase clearly-passable openings.

Tradeoff: marginally slower reaction to "this frontier just became
unreachable because we discovered a wall." In practice, when that
happens the planner fails fast and the BT triggers replanning anyway,
so explore catches up within one cycle.

### Localization: AMCL → slam_toolbox (localization mode)
- **What:** navigation.launch.py no longer launches `nav2_amcl` +
  `nav2_map_server`. Replaced with `slam_toolbox` in
  `mode: localization` (config: `config/slam_toolbox_localization.yaml`).
  One node now provides both the map and the `map → odom` TF.
- **Why:** slam_toolbox's scan-matching localizer is typically more
  accurate and smoother than AMCL on the same environment, and
  slam_toolbox is already a workspace dep so no extra runtime weight.
- **Map format change:** the saved map is now slam_toolbox's
  serialized format (`<basename>.posegraph` + `<basename>.data`), NOT
  the AMCL `.yaml` + `.pgm` pair. The `map:=` launch arg is now a
  base path with NO extension. To produce the files, run mapping mode
  then call:
  ```
  ros2 service call /slam_toolbox/serialize_map slam_toolbox/srv/SerializePoseGraph \
    "{filename: '/home/$USER/.base101/maps/home'}"
  ```

### Progress checker: SimpleProgressChecker → PoseProgressChecker
- **What:** One-line swap in `config/controller.yaml`.
- **Why:** `SimpleProgressChecker` only watches xy translation. A robot
  spinning in place forever (e.g. stuck rotating away from a wall) never
  trips it. `PoseProgressChecker` also watches yaw change, catching that
  failure mode.
- **Params:** kept `required_movement_radius: 0.5` from before; added
  `required_movement_angle: 0.5` (~28°).

### Renamed `smoother_config` → `velocity_smoother_config` in launch files
- Previously the variable name `smoother_config` referred to the
  *velocity* smoother. With a path smoother now in the picture, that's
  confusing. Renamed both, plus added `path_smoother_config`.

## Retro: we approached this wrong

The right bring-up order for a new Nav2 stack is:

1. **SLAM with teleop only.** Drive manually, build a map, save it.
   Validates: lidar → SLAM TF (`map → odom → base_link`),
   `/scan` topic, sim time wiring, robot can actually move under
   teleop. Nothing else runs. No Nav2, no costmap, no controller, no
   exploration.
2. **Nav2 with the saved static map, manual goals.** Map_server +
   AMCL + planner + controller. Tune costmap inflation, controller
   limits, goal tolerances against a known, frozen map. Validates: the
   Nav2 stack itself works on this robot's geometry, with a costmap
   you can inspect statically in RViz.
3. **Semi-known: SLAM + Nav2, manual goals.** Drive to clicked goals
   while SLAM is actively expanding the map. Validates: the
   StaticLayer keeps up with map growth, costmap inflation behaves
   sanely on a still-growing world, `track_unknown_space` decision is
   correct.
4. **Autonomous exploration.** Now add `explore_lite`. By this point
   everything underneath is known-good; if something breaks it's the
   explorer's choice of frontiers or the BT's recovery loops, not the
   stack itself.

What we actually did: jumped to step 4. Every problem we hit
(track_unknown_space, sim-time mismatch, inflation cliff, BT
over-recovery, MPPI compute overhead) was simultaneously broken, and
each one masked the others. A symptom in step 4 could have been
caused by anything in steps 1-3. We spent debugging effort
fault-isolating in a system with N unknown variables instead of N=1.

Concretely, if we'd done step 1 first, we'd have validated SLAM and
the `use_sim_time` plumbing in 15 minutes. Step 2 would have flushed
out the inflation pattern and controller choice without ever
involving SLAM. Step 3 would have exposed the StaticLayer +
track_unknown_space tension as the only new variable. By the time we
got to step 4, exploration would have been the only thing left to
tune.

Lesson for next time (and this is general, not Nav2-specific): when
bringing up a stack of N interacting components, run a bring-up
sequence where each step adds **exactly one** new component on top of
known-good ones. If a step misbehaves, the new thing is the cause.
Skipping ahead to "let's just run the whole stack" trades 15 minutes
of bring-up discipline for hours of fault isolation in a system where
everything is suspect.

## Things deliberately not done

- **`laser_filter`** is configured (LLMy used it to crop body returns)
  but not in any launch. base101's lidar mount is high enough that the
  full 360° is probably usable; revisit if `/scan` shows phantom
  returns at body-shaped angles.
- **EKF integration** — IMU wiring not in scope yet. Configs ready.
- **MoveIt or arm integration** — out of scope for nav.
- **Custom service types** for mode_manager — code has a "Phase 2"
  comment about migrating from Trigger services to typed ones. Not
  done; Trigger works fine for now.

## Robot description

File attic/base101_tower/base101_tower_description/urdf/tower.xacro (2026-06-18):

<?xml version="1.0" ?>
<robot name="base101_tower" xmlns:xacro="http://www.ros.org/wiki/xacro">

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
<xacro:property name="tower_mount_parent" value="top_plate_1"/>
<xacro:property name="tower_mount_xyz" value="0.219384 0.054181 -0.010489"/>

<link name="column_1">
  <inertial>
    <origin xyz="-0.002342141752436938 2.1317594831170295e-05 0.3199294995742388" rpy="0 0 0"/>
    <mass value="10.261070300347177"/>
    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
  </inertial>
  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
</link>

<link name="column_mount_1">
  <inertial>
    <origin xyz="0.6948952845941259 0.006041890428593474 -0.35674292082893144" rpy="0 0 0"/>
    <mass value="0.496601011064834"/>
    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
  </inertial>
  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
</link>

<link name="connector_1">
  <inertial>
    <origin xyz="0.022636855962092764 0.020922452473755078 -0.026435629849796527" rpy="0 0 0"/>
    <mass value="1.2683957427952883"/>
    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
  </inertial>
  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
</link>

<link name="crossbeam_1">
  <inertial>
    <origin xyz="-0.0199997988923723 2.895278907589366e-05 0.009999867922694528" rpy="0 0 0"/>
    <mass value="3.6685435899526917"/>
    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
  </inertial>
  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
</link>

<link name="left_arm_bracket_1">
  <inertial>
    <origin xyz="2.011076230129527e-07 0.06002086437718274 0.0068958886997308455" rpy="0 0 0"/>
    <mass value="1.2932475418133302"/>
    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
  </inertial>
  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
</link>

<link name="right_arm_bracket_1">
  <inertial>
    <origin xyz="2.0110762357847256e-07 -0.059979141810831166 0.007247906927843495" rpy="0 0 0"/>
    <mass value="1.2932475418133291"/>
    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
  </inertial>
  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
</link>

<link name="camera_support_1">
  <inertial>
    <origin xyz="-0.0035446906567737843 -0.00019321279022931764 0.01578740366628728" rpy="0 0 0"/>
    <mass value="0.8331137913549925"/>
    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
  </inertial>
  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
</link>

<link name="head_camera_1">
  <inertial>
    <origin xyz="0.010804302313088689 -0.021386743497499437 -0.006143560713981588" rpy="0 0 0"/>
    <mass value="0.3586641913417661"/>
    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
  </inertial>
  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
</link>

<link name="head_tilt_1">
  <inertial>
    <origin xyz="0.008041821507701335 -0.019691143155115505 0.012149523395599715" rpy="0 0 0"/>
    <mass value="0.22308298230618276"/>
    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
  </inertial>
  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
</link>

<link name="head_tilt_motor_1">
  <inertial>
    <origin xyz="-0.010249798914349005 -0.016027005055545558 0.01999940969737002" rpy="0 0 0"/>
    <mass value="0.28430338235342945"/>
    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
  </inertial>
  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
</link>

<link name="head_pan_thingy_1">
  <inertial>
    <origin xyz="0.011005969879426009 -0.015350146819157591 0.0011421723833012765" rpy="0 0 0"/>
    <mass value="0.1085307375555352"/>
    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
  </inertial>
  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
</link>

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
<link name="head_pan_1">
  <inertial>
    <origin xyz="0.031597 -0.000223 -0.009102" rpy="0 0 0"/>
    <mass value="0.5385469321774147"/>
    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
  </inertial>
  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
</link>

<link name="head_pan_camera_1">
  <inertial>
    <origin xyz="0.016199228662326356 -0.010249940064807901 -0.015772552964165798" rpy="0 0 0"/>
    <mass value="0.2843033831904073"/>
    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
  </inertial>
  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
</link>

<joint name="Rigid 79" type="fixed">
  <origin xyz="${tower_mount_xyz}" rpy="0 0 0"/>
  <parent link="${tower_mount_parent}"/>
  <child link="column_1"/>
</joint>

<joint name="lift" type="prismatic">
  <origin xyz="-0.667476 -0.005932 0.689992" rpy="0 0 0"/>
  <parent link="column_1"/>
  <child link="column_mount_1"/>
  <axis xyz="-0.0 -0.0 -1.0"/>
  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
  <limit upper="0.26" lower="-0.26" effort="400" velocity="0.5"/>
</joint>

<joint name="Rigid 80" type="fixed">
  <origin xyz="0.701476 -0.015068 -0.330742" rpy="0 0 0"/>
  <parent link="column_mount_1"/>
  <child link="connector_1"/>
</joint>

<joint name="Rigid 81" type="fixed">
  <origin xyz="0.0495 0.020899 -0.034561" rpy="0 0 0"/>
  <parent link="connector_1"/>
  <child link="crossbeam_1"/>
</joint>

<joint name="Rigid 82" type="fixed">
  <origin xyz="-0.02 -0.292081 0.000857" rpy="0 0 0"/>
  <parent link="crossbeam_1"/>
  <child link="left_arm_bracket_1"/>
</joint>

<joint name="Rigid 83" type="fixed">
  <origin xyz="-0.02 0.29208 -0.000857" rpy="0 0 0"/>
  <parent link="crossbeam_1"/>
  <child link="right_arm_bracket_1"/>
</joint>

<joint name="Rigid 84" type="fixed">
  <origin xyz="0.0 0.0 0.64" rpy="0 0 0"/>
  <parent link="column_1"/>
  <child link="camera_support_1"/>
</joint>

<joint name="Rigid 85" type="fixed">
  <origin xyz="0.023476 0.0028 0.017125" rpy="0 0 0"/>
  <parent link="head_tilt_1"/>
  <child link="head_camera_1"/>
</joint>

<joint name="head_tilt" type="continuous">
  <origin xyz="-0.01025 0.0018 0.0328" rpy="0 0 0"/>
  <parent link="head_tilt_motor_1"/>
  <child link="head_tilt_1"/>
  <axis xyz="-0.0 1.0 0.0"/>
</joint>

<joint name="Rigid 87" type="fixed">
  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
  <origin xyz="0.040891 0.016349 0.019838" rpy="0 0 0"/>
  <parent link="head_pan_1"/>
  <child link="head_tilt_motor_1"/>
</joint>

<joint name="Rigid 88" type="fixed">
  <origin xyz="-0.0205 0.0 0.0" rpy="0 0 0"/>
  <parent link="head_tilt_motor_1"/>
  <child link="head_pan_thingy_1"/>
</joint>

<joint name="head_pan" type="continuous">
  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
  <origin xyz="0.028959 -0.010299 0.004362" rpy="0 0 0"/>
  <parent link="head_pan_camera_1"/>
  <child link="head_pan_1"/>
  <axis xyz="0.0 0.0 1.0"/>
</joint>

<joint name="Rigid 90" type="fixed">
  <origin xyz="-0.00615 0.00958 0.06" rpy="0 0 0"/>
  <parent link="camera_support_1"/>
  <child link="head_pan_camera_1"/>
</joint>

</robot>

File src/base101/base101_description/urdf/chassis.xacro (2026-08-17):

<?xml version="1.0" ?>
<robot name="base101_chassis" xmlns:xacro="http://www.ros.org/wiki/xacro">

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

<xacro:arg name="camera" default="realsense"/>

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

<link name="base_link">
  <inertial>
    <origin xyz="-0.00433828 0 0.083465" rpy="0 0 0"/>
    <mass value="1.81049"/>
    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
  </inertial>
  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
</link>

<link name="box_front_1">
  <inertial>
    <origin xyz="-0.00962595 0 -0.03" rpy="0 0 0"/>
    <mass value="0.740521"/>
    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
  </inertial>
  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
</link>

<link name="box_back_1">
  <inertial>
    <origin xyz="0.00962595 0 -0.03" rpy="0 0 0"/>
    <mass value="0.740521"/>
    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
  </inertial>
  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
</link>

<link name="box_left_1">
  <inertial>
    <origin xyz="-0.17 -0.00974265 -0.0299929" rpy="0 0 0"/>
    <mass value="1.07632"/>
    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
  </inertial>
  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
</link>

<link name="box_right_1">
  <inertial>
    <origin xyz="-0.17 0.00974265 -0.0299929" rpy="0 0 0"/>
    <mass value="1.07632"/>
    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
  </inertial>
  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
</link>

<joint name="box_front_joint" type="fixed">
  <origin xyz="0.17 0 0.081965" rpy="0 0 0"/>
  <parent link="base_link"/>
  <child link="box_front_1"/>
</joint>

<joint name="box_back_joint" type="fixed">
  <origin xyz="-0.17 0 0.081965" rpy="0 0 0"/>
  <parent link="base_link"/>
  <child link="box_back_1"/>
</joint>

<joint name="box_left_joint" type="fixed">
  <origin xyz="0.17 0.12 0.081965" rpy="0 0 0"/>
  <parent link="base_link"/>
  <child link="box_left_1"/>
</joint>

<joint name="box_right_joint" type="fixed">
  <origin xyz="0.17 -0.12 0.081965" rpy="0 0 0"/>
  <parent link="base_link"/>
  <child link="box_right_1"/>
</joint>

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

<link name="mount_front_left_1">
  <inertial>
    <origin xyz="0.0252801 0.00623325 -0.00938469" rpy="0 0 0"/>
    <mass value="0.120821"/>
    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
  </inertial>
  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
</link>

<link name="mount_front_right_1">
  <inertial>
    <origin xyz="-0.0245929 -0.00623325 -0.00938469" rpy="0 0 0"/>
    <mass value="0.120821"/>
    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
  </inertial>
  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
</link>

<link name="mount_back_left_1">
  <inertial>
    <origin xyz="-0.0245932 0.00623325 -0.00938469" rpy="0 0 0"/>
    <mass value="0.120821"/>
    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
  </inertial>
  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
</link>

<link name="mount_back_right_1">
  <inertial>
    <origin xyz="0.0252798 -0.00623325 -0.00938469" rpy="0 0 0"/>
    <mass value="0.120821"/>
    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
  </inertial>
  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
</link>

<joint name="mount_front_left_joint" type="fixed">
  <origin xyz="-0.07531 0 -0.03958" rpy="0 0 0"/>
  <parent link="box_left_1"/>
  <child link="mount_front_left_1"/>
</joint>

<joint name="mount_front_right_joint" type="fixed">
  <origin xyz="-0.025437 0 -0.03958" rpy="0 0 0"/>
  <parent link="box_right_1"/>
  <child link="mount_front_right_1"/>
</joint>

<joint name="mount_back_left_joint" type="fixed">
  <origin xyz="-0.26469 0 -0.03958" rpy="0 0 0"/>
  <parent link="box_left_1"/>
  <child link="mount_back_left_1"/>
</joint>

<joint name="mount_back_right_joint" type="fixed">
  <origin xyz="-0.314563 0 -0.03958" rpy="0 0 0"/>
  <parent link="box_right_1"/>
  <child link="mount_back_right_1"/>
</joint>

<link name="wheel_hub_front_left_1">
  <inertial>
    <origin xyz="2.42448e-07 0.0045847 -7.68714e-05" rpy="0 0 0"/>
    <mass value="0.0207465"/>
    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
  </inertial>
  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
</link>

<link name="wheel_front_left_1">
  <inertial>
    <origin xyz="2.41449e-07 0.01605 4.80462e-08" rpy="0 0 0"/>
    <mass value="0.53737"/>
    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
  </inertial>
  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
</link>

<joint name="wheel_hub_front_left_joint" type="fixed">
  <origin xyz="0.025367 0.0089 -0.006387" rpy="0 0 0"/>
  <parent link="mount_front_left_1"/>
  <child link="wheel_hub_front_left_1"/>
</joint>

<joint name="front_left_wheel_joint" type="continuous">
  <origin xyz="0 0 0" rpy="0 0 0"/>
  <parent link="wheel_hub_front_left_1"/>
  <child link="wheel_front_left_1"/>
  <axis xyz="0 1 0"/>
</joint>

<link name="wheel_hub_front_right_1">
  <inertial>
    <origin xyz="2.42448e-07 -0.0045847 -7.68714e-05" rpy="0 0 0"/>
    <mass value="0.0207465"/>
    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
  </inertial>
  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
</link>

<link name="wheel_front_right_1">
  <inertial>
    <origin xyz="2.41449e-07 -0.01605 4.80462e-08" rpy="0 0 0"/>
    <mass value="0.53737"/>
    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
  </inertial>
  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
</link>

<joint name="wheel_hub_front_right_joint" type="fixed">
  <origin xyz="-0.024506 -0.0089 -0.006387" rpy="0 0 0"/>
  <parent link="mount_front_right_1"/>
  <child link="wheel_hub_front_right_1"/>
</joint>

<joint name="front_right_wheel_joint" type="continuous">
  <origin xyz="0 0 0" rpy="0 0 0"/>
  <parent link="wheel_hub_front_right_1"/>
  <child link="wheel_front_right_1"/>
  <axis xyz="0 1 0"/>
</joint>

<link name="wheel_hub_back_left_1">
  <inertial>
    <origin xyz="-1.253e-07 0.0045847 -7.68712e-05" rpy="0 0 0"/>
    <mass value="0.0207465"/>
    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
  </inertial>
  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
</link>

<link name="wheel_back_left_1">
  <inertial>
    <origin xyz="-1.25153e-07 0.01605 4.79703e-08" rpy="0 0 0"/>
    <mass value="0.53737"/>
    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
  </inertial>
  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
</link>

<joint name="wheel_hub_back_left_joint" type="fixed">
  <origin xyz="-0.024506 0.0089 -0.006387" rpy="0 0 0"/>
  <parent link="mount_back_left_1"/>
  <child link="wheel_hub_back_left_1"/>
</joint>

<joint name="back_left_wheel_joint" type="continuous">
  <origin xyz="0 0 0" rpy="0 0 0"/>
  <parent link="wheel_hub_back_left_1"/>
  <child link="wheel_back_left_1"/>
  <axis xyz="0 1 0"/>
</joint>

<link name="wheel_hub_back_right_1">
  <inertial>
    <origin xyz="-1.253e-07 -0.0045847 -7.68712e-05" rpy="0 0 0"/>
    <mass value="0.0207465"/>
    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
  </inertial>
  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
</link>

<link name="wheel_back_right_1">
  <inertial>
    <origin xyz="-1.25153e-07 -0.01605 4.79703e-08" rpy="0 0 0"/>
    <mass value="0.53737"/>
    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
  </inertial>
  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
</link>

<joint name="wheel_hub_back_right_joint" type="fixed">
  <origin xyz="0.025367 -0.0089 -0.006387" rpy="0 0 0"/>
  <parent link="mount_back_right_1"/>
  <child link="wheel_hub_back_right_1"/>
</joint>

<joint name="back_right_wheel_joint" type="continuous">
  <origin xyz="0 0 0" rpy="0 0 0"/>
  <parent link="wheel_hub_back_right_1"/>
  <child link="wheel_back_right_1"/>
  <axis xyz="0 1 0"/>
</joint>

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

<link name="bumper_front_left_1">
  <inertial>
    <origin xyz="0.00320947 -0.00742985 -0.0302987" rpy="0 0 0"/>
    <mass value="0.71387"/>
    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
  </inertial>
  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
</link>

<link name="bumper_front_right_1">
  <inertial>
    <origin xyz="0.00320947 0.00742985 -0.0302987" rpy="0 0 0"/>
    <mass value="0.71387"/>
    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
  </inertial>
  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
</link>

<link name="bumper_back_left_1">
  <inertial>
    <origin xyz="-0.00320951 -0.0074299 -0.0302986" rpy="0 0 0"/>
    <mass value="0.713868"/>
    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
  </inertial>
  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
</link>
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

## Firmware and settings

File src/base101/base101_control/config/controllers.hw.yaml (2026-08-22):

# Hardware controllers for the real robot (base101.hardware.xacro +
# base101_control_plugin/ROS2ControlBridge -> Axon 2 firmware over zenoh).
# Same topology as sim, use_sim_time:=false.
#
# update_rate matches the firmware's joint_states / base_cmd loop (50 Hz,
# AXON_JOINT_STATES_RATE_HZ) so read()/write() don't outrun the bus.
# Geometry below is the simple (DDSM210) variant; override for pro.
#
# NOTE: there are no arm entries here yet. The arm has no hardware
# interface — base101.hardware.xacro emits a ros2_control block for the four
# wheel joints only, so there is nothing for an arm controller to claim.
# base101_bringup_hw rejects arm:=true for that reason. Adding the arm means
# a mod101 SystemInterface (or a second ROS2ControlBridge instance) in the
# hardware xacro first, then mirroring the arm block from controllers.sim.yaml.
controller_manager:
  ros__parameters:
    update_rate: 50
    use_sim_time: false

    joint_state_broadcaster:
      type: joint_state_broadcaster/JointStateBroadcaster

    diff_drive_controller:
      type: diff_drive_controller/DiffDriveController

diff_drive_controller:
  ros__parameters:
    left_wheel_names:  ['front_left_wheel_joint',  'back_left_wheel_joint']
    right_wheel_names: ['front_right_wheel_joint', 'back_right_wheel_joint']

    # simple (DDSM210); for pro (DDSM115) use 0.38 / 0.05035. Refine on the
    # physical robot — these match controllers.sim.yaml.
    wheel_separation: 0.2886  # m
    wheel_radius:     0.0363  # m — 72.6 mm DDSM210 wheel diameter / 2

    position_feedback: true
    odom_frame_id: odom
    base_frame_id: base_link
    enable_odom_tf: true
    publish_rate: 50.0

    # The firmware does not stamp base_cmd; diff_drive's own watchdog stops the
    # wheels if cmd_vel goes stale (twist_mux feeds /diff_drive_controller/cmd_vel).
    cmd_vel_timeout: 0.5

    linear.x.has_velocity_limits:     true
    linear.x.max_velocity:            0.5
    linear.x.min_velocity:           -0.5
    angular.z.has_velocity_limits:     true
    angular.z.max_velocity:            1.5
    angular.z.min_velocity:           -1.5

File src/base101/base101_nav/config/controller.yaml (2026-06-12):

# MPPI controller for the base101 differential drive base.
#
# Adopted from TurtleBot4's nav2.yaml (which itself follows nav2_bringup
# defaults). Velocity caps raised to match base101's hardware envelope.
# Critic weights left at canonical values — they are well-tuned for
# generic diff-drive indoor navigation; only revisit if a specific
# behavior is wrong.

controller_server:
  ros__parameters:
    enable_stamped_cmd_vel: true
    controller_frequency: 20.0          # Nav2 default
    costmap_update_timeout: 0.30
    min_x_velocity_threshold: 0.001
    min_y_velocity_threshold: 0.5       # Not used for diff drive
    min_theta_velocity_threshold: 0.001
    failure_tolerance: 0.3
    use_realtime_priority: false
    progress_checker_plugins: ["progress_checker"]
    goal_checker_plugins: ["general_goal_checker"]
    controller_plugins: ["FollowPath"]

    # PoseProgressChecker catches "spinning forever in place" — SimpleProgressChecker
    # only watches translation, so a robot that keeps rotating without moving xy
    # never trips it. PoseProgressChecker tracks pose delta (xy AND yaw).
    progress_checker:
      plugin: "nav2_controller::PoseProgressChecker"
      required_movement_radius: 0.5
      required_movement_angle: 0.5      # ~28 deg
      movement_time_allowance: 10.0

    general_goal_checker:
      stateful: True
      plugin: "nav2_controller::SimpleGoalChecker"
      xy_goal_tolerance: 0.25
      yaw_goal_tolerance: 0.25

    FollowPath:
      plugin: "nav2_mppi_controller::MPPIController"
      time_steps: 56
      model_dt: 0.05
      batch_size: 1000                    # halved from canonical 2000 — RTF win, marginal quality hit

      # Acceleration limits — kept at hw caps (controllers.simple.sim.yaml
      # gives linear 2.5, angular 3.5; bumped az for snappier rotation onset).
      ax_max: 2.5
      ax_min: -2.5
      ay_max: 2.5
      az_max: 3.5

      # Sampling noise — canonical TB4 values.
      vx_std: 0.2
      vy_std: 0.2
      wz_std: 0.4

      # Velocity envelope. Limits chosen for the simple variant (DDSM210,
      # 72.6 mm wheel, 210 RPM motor cap → ~0.8 m/s real maximum).
      # PRO variant can do ~1.5 m/s — bump vx_max if testing on pro.
      # wz_max/vx_max reconciled to measured limits (Phase 5 tracker item).
      vx_max: 0.5   # measured: DDSM210 rated-speed reality
      vx_min: -0.30
      vy_max: 0.0                       # diff drive, no lateral
      wz_max: 1.5   # matches profile/diff_drive clamp

      iteration_count: 1
      prune_distance: 1.7
      transform_tolerance: 0.1
      temperature: 0.3
      gamma: 0.015
      motion_model: "DiffDrive"
      visualize: true
      regenerate_noises: true
      TrajectoryVisualizer:
        trajectory_step: 5
        time_step: 3
      AckermannConstraints:
        min_turning_r: 0.2

      critics:
        - "ConstraintCritic"
        - "CostCritic"
        - "GoalCritic"
        - "GoalAngleCritic"
        - "PathAlignCritic"
        - "PathFollowCritic"
        - "PathAngleCritic"
        - "PreferForwardCritic"

      ConstraintCritic:
        enabled: true
        cost_power: 1
        cost_weight: 4.0

      GoalCritic:
        enabled: true
        cost_power: 1
        cost_weight: 5.0
        threshold_to_consider: 1.4

      # Bumped weight 3.0 -> 6.0 — converges yaw faster, reduces orbiting/overshoot.
      GoalAngleCritic:
        enabled: true
        cost_power: 1
        cost_weight: 6.0
        threshold_to_consider: 0.5

      PreferForwardCritic:
        enabled: true
        cost_power: 1
        cost_weight: 5.0
        threshold_to_consider: 0.5

      # CostCritic uses the local_costmap directly — no need to mirror
      # inflation params here (that was an RPP requirement).
      CostCritic:
        enabled: true
        cost_power: 1
        cost_weight: 3.81
        critical_cost: 300.0
        consider_footprint: true
        collision_cost: 1000000.0
        near_goal_distance: 1.0
        trajectory_point_step: 2

      PathAlignCritic:
        enabled: true
        cost_power: 1
        cost_weight: 14.0
        max_path_occupancy_ratio: 0.05
        trajectory_point_step: 4
        threshold_to_consider: 0.5
        offset_from_furthest: 20
        use_path_orientations: false

      PathFollowCritic:
        enabled: true
        cost_power: 1
        cost_weight: 5.0
        offset_from_furthest: 5
        threshold_to_consider: 1.4

      PathAngleCritic:
        enabled: true
        cost_power: 1
        cost_weight: 2.0
        offset_from_furthest: 4
        threshold_to_consider: 0.5
        max_angle_to_furthest: 1.0
        mode: 0

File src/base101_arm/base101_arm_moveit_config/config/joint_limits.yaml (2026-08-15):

# Adapted from mod101_moveit_config/config/joint_limits.yaml. Keys are the group and
# joint names as they appear on the composed robot: the mod101 macro is
# instantiated with prefix `arm_`, so group `arm` becomes `arm_arm` and
# joint `joint_base` becomes `arm_joint_base`.
# Velocity / acceleration limits for MoveIt's time parameterisation (TOTG).
#
# The URDF carries effort="100" velocity="100" on every joint — placeholder
# values from the CAD export, not real servo data. TOTG takes velocity and
# acceleration straight from here, so leaving those in place yields trajectories
# that ask for ~100 rad/s and are physically meaningless.
#
# These are deliberately CONSERVATIVE estimates for the Feetech STS/ST3215-class
# servos: no-load spec is roughly 0.16 s/60deg (~6.5 rad/s), but that collapses
# under load and the printed brackets don't enjoy the jerk. Start slow, raise
# once the arm is calibrated and you've watched it track.
#
# The calibration wizard (docs/calibration.md) measures per-joint travel; when
# calibration.yaml lands, position limits should come from there and this file
# should keep only the dynamics.
joint_limits:
  arm_joint_base:
    has_velocity_limits: true
    max_velocity: 1.5
    has_acceleration_limits: true
    max_acceleration: 3.0

  # Shoulder carries the whole arm plus payload — the joint most likely to stall
  # and the one the configurator flags as the payload-limiting joint.
  arm_joint_shoulder:
    has_velocity_limits: true
    max_velocity: 1.0
    has_acceleration_limits: true
    max_acceleration: 2.0

  arm_joint_elbow:
    has_velocity_limits: true
    max_velocity: 1.2
    has_acceleration_limits: true
    max_acceleration: 2.5

  arm_joint_wrist_tilt:
    has_velocity_limits: true
    max_velocity: 1.5
    has_acceleration_limits: true
    max_acceleration: 3.0

  arm_joint_wrist_roll:
    has_velocity_limits: true
    max_velocity: 2.0
    has_acceleration_limits: true
    max_acceleration: 4.0

  # Tool drive joint: "6" in every mod101_tool_* package, arm_6 once prefixed.
  arm_6:
    has_velocity_limits: true
    max_velocity: 1.0
    has_acceleration_limits: true
    max_acceleration: 2.0

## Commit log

2026-05-18 navigating, exploring, etc
    [controller.yaml, controllers.pro.sim.yaml, controllers.simple.sim.yaml]
2026-05-18 navigation and exploration almost there
    [controller.yaml, empty.sdf, sticky_floor.sdf]
2026-05-19 added mujuco and isaac
    [base101.hardware.xacro, base101.xacro, base101_pro.xacro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]
2026-06-11 added dual arm setup
    [base101.hardware.xacro, base101.xacro, base101_arms.xacro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]
2026-06-11 robocore Phase 1: add robocore_agent package (tracker: Phase 1 transport/handshake)
    Generic JSON-RPC/WebSocket agent node: profile loader (stub),
    asyncio server on unix socket + TCP, hello/ping/debug.send_payload
    handlers, rclpy node skeleton. Zero robot-specific code.
    Also: COLCON_IGNORE markers for mujoco/isaac packages (out of scope
    for now, per Cristi - Gazebo only) and the Phase 1 worklog.
2026-06-11 robocore Phase 2: agent core - audit log, task model, safety skeleton, profile validation (tracker: Phase 2)
    Profile loading now validates against the shared RobotProfile schema.
    New: AuditLog (ring + JSONL at ~/.robocore/audit/<robot>, rotation),
    TaskManager (task.update notifications to owner, cancel), SafetyLayer
    (e-stop + motion lock on MOTION_METHODS, checked in dispatch),
    mobility.navigate_to stub, debug.set_estop / debug.run_task,
    audit.query/subscribe, bootstrap.build_agent wiring.
2026-06-11 robocore Phase 3: agent ROS interface, TF, mobility state, teleop (tracker: Phase 3)
    RosInterface (rclpy quarantined here): odom sub (BEST_EFFORT QoS),
    cmd_vel pub (TwistStamped per profile cmd_vel_stamped), TF buffer,
    MultiThreadedExecutor. TeleopManager: motion lock, profile-clamped
    velocity, server watchdog, disconnect cleanup. stop_on_disconnect.
    twist_mux gains /cmd_vel_agent input (priority 50).
    Two silent-drop ROS bugs fixed (see engine worklog): odom RELIABLE vs
    BEST_EFFORT publisher; cmd_vel Twist vs TwistStamped (Jazzy twist_mux
    use_stamped). Verified live: robot drove 0.64 m under teleop.
2026-06-12 robocore Phase 4 agent: shm store, frame cache + deproject/clouds, sensor subs, watch sampler with stop-halt, streams, events; additive depth sensor on base_camera
2026-06-12 robocore agent: latest-value sensor family (range/imu/mag/wrench/env/diagnostics), full BatteryState, intrinsics distortion, lidar range bounds + intensities, expanded watch paths
2026-06-12 base101 nav restructure: split into base101_slam + pure-Nav2 base101_nav for robocore autonomy
    Per bpe/nav_setup.md. SLAM/EKF move to a new independent base101_slam
    package (own lifecycle manager, no cross-dependency with nav); base101_nav
    becomes pure Nav2 (planner/controller/bt_navigator/velocity_smoother).
    One always-on launch each, mode switching via slam_toolbox services (not
    process restarts), minimal plan/follow/fail BTs, no behavior_server, no
    AMCL, no explore_lite, no mode_manager. Unified costmap + slam_toolbox
    configs. Sim gains an IMU on base_link (feeds EKF + robocore imu API).
    slam lifecycle manager uses bond_timeout 0.0 (the bond heartbeat misfires
    under sim time); nav_throug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
    [empty.sdf]
2026-06-12 robocore Phase 5 agent: Nav2 action client + nav task, slam manager (modes/save/load/localize/quality), places store; velocity limits reconciled to measured (0.5 m/s, 1.5 rad/s)
    [controller.yaml, controllers.simple.sim.yaml]
2026-06-12 slam.save: export the 2D grid as png (map_saver_cli --fmt png) — viewable anywhere, map_io loads it the same
2026-06-13 nav costmap: shrink inflation 0.55->0.35 m, steepen cost_scaling 3->5
    0.55 m at 0.05 m/cell was 11 cells of inflation around every obstacle —
    on a robot with a 0.24 m inscribed radius that closed off any gap under
    ~1.1 m, so the planner had nowhere to go in the sim. 0.35 m clears the
    body with a small buffer; cost_scaling 5.0 keeps the high-cost band thin
    so it threads real gaps while still preferring corridor centers.
2026-06-13 nav costmap: inflation 0.35->0.40 m, above the 0.3607 m circumscribed floor
    inflation_radius below the footprint's circumscribed radius (0.3607 m)
    makes Nav2 disable the potential-field collision-check shortcut and warn
    that planning will crawl. 0.40 clears that floor while staying well under
    the original 0.55. Inflating less means shrinking the footprint, not the
    radius.
2026-06-13 nav costmap: real measured footprint (0.18x0.15 half-extents), inflation 0.40->0.30
    The footprint was 0.25x0.24 half-extents (~0.5x0.48 m) — roughly double
    the real robot. Measured from the URDF joint tree: bumpers x -0.165..+0.175,
    outside wheels y +/-0.144, so the body is ~0.34x0.29 m. New circumscribed
    radius ~0.245 m lets inflation drop to 0.30 (was forced to 0.40+ by the
    bogus footprint). Gaps down to ~0.30 m are now passable.
2026-06-18 major restructuring
    [arm.xacro, arm_mount.xacro, arm_mount_plate.stl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]
2026-08-15 where do I even start
    [arm.xacro, arm_mount.xacro, arm_mount_plate.stl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]
2026-08-15 added moveit
    [base101.xacro, base_link.stl, box_back_1.stl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]
2026-08-17 progress on the arm and Moveit
    [jaws.srdf.xacro, none.srdf.xacro, parallel.srdf.xacro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]
2026-08-17 changed bumpers, integrated moveit, nicer readme
    [bumper_assembly.stl, bumper_back_left_1.stl, bumper_back_right_1.stl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]
2026-08-17 tweaks to the readme
    [bumper_assembly.stl]
2026-08-22 get nav and slam back, package reorg
    [arm.xacro, base101.hardware.xacro, base101_arm.xacro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]
2026-08-22 agent is back
    [arm.xacro, base101.hardware.xacro, base101.xacro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]
2026-08-24 changes to match the shape of bpe
    [controllers.sim.yaml]
2026-08-26 added laserfilter to ignore parts of it's own body
